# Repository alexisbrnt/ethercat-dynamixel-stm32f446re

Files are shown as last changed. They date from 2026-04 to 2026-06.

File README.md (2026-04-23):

# EtherCAT Communication for Dynamixel by STM32F446RE

> An embedded **EtherCAT slave node** built around the STM32F446RE, driving a Dynamixel XM430-W350 servomotor in real time.

---

## About

An embedded EtherCAT slave node based on the **STM32F446RE** microcontroller, designed to drive a **Dynamixel XM430-W350** servomotor through the Dynamixel Protocol 2.0. The STM32 interfaces with an EtherCAT master over SPI (via a LAN9252 slave controller) and translates incoming commands into UART/RS-485 frames sent to the motor.

This project is developed as part of an internship at **Heemskerk Innovative Technology (HIT)**, Delft, The Netherlands.

---

## Goal

Design and implement a new real-time communication architecture allowing an EtherCAT master to command a Dynamixel servomotor (position, velocity, etc.) and read back its live telemetry (position, velocity, current, temperature) with deterministic timing.

**Data path:**

```
EtherCAT Master  ──►  LAN9252 (SPI slave)  ──►  STM32F446RE  ──►  MAX485  ──►  Dynamixel XM430-W350
```

---

## Hardware

| Component | Reference |
|---|---|
| Microcontroller | STM32F446RE (ARM Cortex-M4 @ 180 MHz, 512 KB Flash, 128 KB SRAM) |
| Development board | Nucleo-F446RE (integrated ST-LINK) |
| EtherCAT slave controller | **EVB-LAN9252-SPI** (Microchip evaluation board) |
| Motor | Dynamixel XM430-W350 (Protocol 2.0) |
| UART ↔ RS-485 transceiver | MAX485 |
| Motor power supply | SMPS2Dynamixel |

---

## STM32F446RE Pinout

### Dynamixel communication (UART + RS-485)

| STM32 Pin | Function | Connected to |
|---|---|---|
| **PA9** | UART TX | MAX485 DI |
| **PA10** | UART RX | MAX485 RO |
| **PB3** | DE/RE (RS-485 direction control) | MAX485 DE + RE |

### EtherCAT communication (SPI to LAN9252)

| STM32 Pin | Function | Connected to |
|---|---|---|
| **PA5** | SPI SCK | LAN9252 SCK |
| **PA6** | SPI MISO | LAN9252 MISO |
| **PA7** | SPI MOSI | LAN9252 MOSI |
| **PB6** | SPI CS | LAN9252 CS |

---

## Configuration

| Parameter | Value |
|---|---|
| UART baudrate (STM32 ↔ Dynamixel) | **3,000,000 bauds** (3 Mbps) |
| Dynamixel protocol | **2.0** |
| Default motor ID | **1** |
| SPI frequency (STM32 ↔ LAN9252) | **11.25 MHz** |
| EtherCAT cycle time | **2 ms** |

---

## Usage

### 1. Flash the LAN9252 EEPROM (one-time setup)

Before the EtherCAT master can discover the slave with the correct identity (vendor ID, product code, PDO mapping, etc.), the LAN9252 EEPROM must be programmed with the project's ESI (EtherCAT Slave Information) binary.

The EEPROM image is provided in the firmware sources:

```
STM32_dynamixel/Src/ECAT/soes-esi/eeprom.hex
```

Flash it with the `eepromtool` utility provided by [SOEM](https://github.com/OpenEtherCATsociety/SOEM):

```bash
sudo ./eepromtool <your_network_interface> 1 -wi eeprom.hex
```

- The first argument `1` is the EtherCAT slave position on the bus.
- Replace `<your_network_interface>` (e.g. `eth0`) with the interface connected to the LAN9252.

This step is only required **once per LAN9252 board**, or whenever the ESI / PDO mapping is changed.

### 2. Build and flash the STM32 firmware

1. Open **STM32CubeIDE** 
2. `File → Open Projects from File System…` and select the `firmware/` folder.
3. Build the project: `Project → Build Project` (or `Ctrl+B`).
4. Connect the Nucleo-F446RE over USB and flash: `Run → Run` (or `F11` for debug mode).

### 3. Run the EtherCAT master and GUI

The `ec_motor.py` script is a single-program tool that launches the **EtherCAT master** (using `pysoem`) and a **PyQt5 graphical interface** in the same process. The master runs its cyclic loop (2 ms period) in a dedicated thread and communicates with the GUI through Qt signals.

The GUI allows the user to:

- select the motor **ID** and **control mode** (Position or Velocity),
- set a **target position** (0–4095) or **target velocity** (−200 to +200) through sliders,
- toggle the **torque** and the **LED** on the motor,
- monitor in real time the **present position, velocity, current, temperature**, the motor **state** (`IDLE`, `INIT`, `READY`, `RUNNING`, `ERROR`, `OFF`), the current **operating mode** and the **baudrate**.

**Dependencies** (tested on Linux, Ubuntu/Debian):

```bash
pip install -r scripts/requirements.txt
```

**Launch** (from the root of the repository):

```bash
sudo python3 scripts/ec_motor.py --ifname <your_network_interface>
```

#### Network interface — must be adapted to your machine

The EtherCAT master binds to a specific network interface (the one physically connected to the EtherCAT slave, typically a USB-to-Ethernet adapter). The interface name depends on your hardware and operating system, so **it must be changed in two places**:

1. In the **launch command**, via the `--ifname` argument.
2. In the **default value** inside `scripts/ec_motor.py` (the current hardcoded default is the interface used during development and will not match your setup).

To find the name of your own interface on Linux:

```bash
ip link show
```

Look for an entry matching the adapter you plugged in (often starting with `enx...` for USB-to-Ethernet, or `eth...` / `enp...` for built-in Ethernet).

**Other notes:**

- `sudo` is required because the EtherCAT master sends raw Ethernet frames directly on the network interface.

---

## Resources & references

- [Dynamixel XM430-W350 e-Manual](https://emanual.robotis.com/docs/en/dxl/x/xm430-w350/)
- [Dynamixel Protocol 2.0](https://emanual.robotis.com/docs/en/dxl/protocol2/)
- [STM32F446RE datasheet](https://www.st.com/en/microcontrollers-microprocessors/stm32f446re.html)
- [Microchip LAN9252 product page](https://www.microchip.com/en-us/product/lan9252)
- [EtherCAT Technology Group (ETG)](https://www.ethercat.org/)

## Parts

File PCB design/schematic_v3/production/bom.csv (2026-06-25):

Designator | Footprint | Quantity | Value | LCSC Part #
C1, C11, C13, C15, C16, C17, C20, C21, C24, C25, C27, C28, C31, C34, C35, C38, C40, C41, C42, C43, C45, C5 | 603 | 22 | 100n | C1525
C10 | 603 | 1 | 1n | C1588
C12, C18, C19, C36 | 603 | 4 | 1u | C15849
C14 | 603 | 1 | 470p | C1620
C2, C3, C4, C6 | 603 | 4 | 10p | C1634
C22, C23 | 603 | 2 | 18p | C1647
C26 | CP_Elec_5x5.4 | 1 | 47u | C7469972
C29, C39, C50 | 1206 | 3 | 10u | C13585
C30 | 1206 | 1 | 100n | C24497
C32, C33 | 603 | 2 | 27p | C107045
C37 | 603 | 1 | 4.7u | C19666
C44 | 603 | 1 | 270p | C1608
C46, C48 | C_Elec_4x5.8 | 2 | 27u | C413624
C47, C49 | 1206 | 2 | 22u | C12891
C51 | 603 | 1 | 56p | C107053
C7 | 603 | 1 | 0.022u | C21122
C8 | CP_Elec_5x5.4 | 1 | 10u | C7469956
C9 | CP_Elec_4x5.4 | 1 | 1u | C3348
D1, D2 | D_SOD-323F | 2 | PMEG3020EJ | C7472895
D3, D8 | SOT-143 | 2 | PRTR5V0U2X | C2827688
D4 | 603 | 1 | LED_Small | C2286
D5 | 603 | 1 | LED_Small | C2287
D6 | 603 | 1 | LED_Small | C2288
D7 | 603 | 1 | LED_Small | C2289
F1 | 2920L150_60MR | 1 | 2920L150_60MR | C22504886
FB1, FB2, FB3, FB4 | IND_BLM18_0603_MUR | 4 | BLM18EG221SN1D | C85827
FB5 | MMZ0603A471ET000 | 1 | MMZ0603A471ET000 | C502003
IC1 | LAN9252 | 1 | LAN9252 | C2758355
IC2 | MP5000ADQ-LF-Z | 1 | MP5000ADQ-LF-Z | C17698177
J1 | JST_EH_B4B-EH-A_1x04_P2.50mm_Vertical | 1 | Conn_01x04_Pin | C160258
J2 | JST_EH_B2B-EH-A_1x02_P2.50mm_Vertical | 1 | Conn_01x02_Pin | C160262
J3 | JST_EH_B4B-EH-A_1x04_P2.50mm_Vertical | 1 | connection_moteur | C160258
J4 | PinHeader_1x05_P1.27mm_Vertical | 1 | Conn_01x05_Pin | C22438102
J5 | JST_EH_B3B-EH-A_1x03_P2.50mm_Vertical | 1 | Conn_01x03_Pin | C160259
L1 | L_Bourns_SRR1260 | 1 | 18u | C2042399
L2 | L_Bourns-SRN4018 | 1 | 6.8u | C2044369
R1 | 603 | 1 | 47k | C25819
R10 | 805 | 1 | 120 | C17437
R11, R12 | 603 | 2 | 75 | C4275
R13 | 603 | 1 | 220 | C22962
R14, R46, R47 | 603 | 3 | 100 | C22775
R15, R17, R18, R24, R26, R27, R29, R3, R31, R37, R43, R44, R45 | 603 | 13 | 10k | C309083
R16 | 603 | 1 | 12.1k | C22864
R19 | 603 | 1 | 4.7k | C23162
R2, R4, R5, R6 | 603 | 4 | 49.9 | C23185
R20, R7 | 603 | 2 | 0 | C21189
R21, R22, R34, R36, R38, R39, R40, R41, R42 | 603 | 9 | 1k | C21190
R23 | 603 | 1 | 68k | C23231
R25, R8, R9 | 603 | 3 | 20k | C4184
R28 | 603 | 1 | 150k | C22807
R30, R32, R33 | 603 | 3 | 33 | C23140
R35 | 603 | 1 | 3.3k | C22978
S1, S2 | B3U1100PM | 2 | B3U-1100PM | C6467298
T1 | 7490100110A | 1 | 7490100110A | C55061081
TP1, TP2, TP3, TP4, TP5, TP6, TP7, TP8, TP9 | TestPoint_Pad_D1.0mm | 9 | TestPoint
U1 | SN74LVC3G17DCTRE4 | 1 | SN74LVC3G17DCTRE4 | C19948350
U3 | 24FC512_I_ST | 1 | 24FC512-I/ST | C619635
U4 | LMR14030SQDPRTQ1 | 1 | LMR14030SQDPRTQ1 | C425925
U5 | LQFP-64_10x10mm_P0.5mm | 1 | STM32F446RETx | C69336
U6 | TSOT-23-6 | 1 | AP63203WU | C780769
U7 | SOIC-8_3.9x4.9mm_P1.27mm | 1 | MAX3485 | C9943
Y2 | ABM3-20.000MHZ-D2Y-T | 1 | ABM3-20.000MHZ-D2Y-T | C596863
Y3 | ABM3-25.000MHZ-D2Y-T | 1 | ABM3-25.000MHZ-D2Y-T | C148312

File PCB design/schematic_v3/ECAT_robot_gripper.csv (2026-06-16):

Reference | Qty | Value | DNP | Exclude from BOM | Exclude from Board | Footprint | Datasheet
C1,C6,C11,C13,C15,C16,C17,C21,C22,C28,C30,C33,C35 | 13 | 0.1u |  |  |  | Capacitor_SMD:C_0603_1608Metric
C2,C3,C4,C5 | 4 | 10p |  |  |  | Capacitor_SMD:C_0603_1608Metric
C7 | 1 | 0.022u |  |  |  | Capacitor_SMD:C_0603_1608Metric
C8,C10,C18 | 3 | 47u |  |  |  | Capacitor_SMD:CP_Elec_5x5.4
C9 | 1 | 1n |  |  |  | Capacitor_SMD:C_0603_1608Metric
C12,C19,C20,C44 | 4 | 1u |  |  |  | Capacitor_SMD:C_0603_1608Metric
C14 | 1 | 470p |  |  |  | Capacitor_SMD:C_0603_1608Metric
C26,C27 | 2 | 18p |  |  |  | Capacitor_SMD:C_0603_1608Metric
C29,C56 | 2 | 10u |  |  |  | Capacitor_SMD:C_1206_3216Metric
C38 | 1 | 100n |  |  |  | Capacitor_SMD:C_1206_3216Metric
C39,C42,C43,C46,C47,C48,C50,C51,C57 | 9 | 100n |  |  |  | Capacitor_SMD:C_0603_1608Metric
C40,C41 | 2 | 20p |  |  |  | Capacitor_SMD:C_0603_1608Metric
C45 | 1 | 4.7u |  |  |  | Capacitor_SMD:C_0603_1608Metric
C52 | 1 | 270p |  |  |  | Capacitor_SMD:C_0603_1608Metric
C53,C55 | 2 | 27u |  |  |  | Capacitor_SMD:C_1206_3216Metric
C58,C59 | 2 | 22u |  |  |  | Capacitor_SMD:C_1206_3216Metric
D1,D2,D3 | 3 | B340 |  |  |  | Diode_SMD:D_SMC | http://www.jameco.com/Jameco/Products/ProdDS/1538777.pdf
FB1,FB2,FB3,FB4 | 4 | BLM18EG221SN1D |  |  |  | footprints:IND_BLM18_0603_MUR | BLM18EG221SN1D
FB5 | 1 | MMZ0603A471ET000 |  |  |  | footprints:MMZ0603A471ET000 | https://product.tdk.com/system/files/dam/doc/product/emc/emc/beads/catalog/beads_commercial_signal_mmz0603-e_en.pdf
IC1 | 1 | LAN9252 |  |  |  | footprints:LAN9252
J1 | 1 | Conn_01x04_Pin |  |  |  | Connector_JST:JST_EH_B4B-EH-A_1x04_P2.50mm_Vertical
J2 | 1 | connection_moteur |  |  |  | Connector_JST:JST_EH_B4B-EH-A_1x04_P2.50mm_Vertical
J3 | 1 | Conn_01x05_Pin |  |  |  | Connector_PinHeader_1.27mm:PinHeader_1x05_P1.27mm_Vertical
J4 | 1 | Conn_01x03_Pin |  |  |  | Connector_PinHeader_1.27mm:PinHeader_1x03_P1.27mm_Vertical
J5 | 1 | Conn_01x02_Pin |  |  |  | Connector_JST:JST_EH_B2B-EH-A_1x02_P2.50mm_Vertical
L1 | 1 | 18u |  |  |  | Inductor_SMD:L_Bourns_SRR1260
L3 | 1 | 6.8u |  |  |  | Inductor_SMD:L_Bourns-SRN4018
Q1 | 1 | AO3400A |  |  |  | Package_TO_SOT_SMD:SOT-23 | http://www.aosmd.com/pdfs/datasheet/AO3400A.pdf
R1,R4,R5,R6 | 4 | 49.9 |  |  |  | Resistor_SMD:R_0603_1608Metric
R2 | 1 | 47k |  |  |  | Resistor_SMD:R_0603_1608Metric
R3,R14,R15,R17,R18,R24,R26,R27,R29,R31 | 10 | 10k |  |  |  | Resistor_SMD:R_0603_1608Metric
R7,R20 | 2 | 0 |  |  |  | Resistor_SMD:R_0603_1608Metric
R8,R9,R25 | 3 | 20k |  |  |  | Resistor_SMD:R_0603_1608Metric
R10 | 1 | 120 |  |  |  | Resistor_SMD:R_0805_2012Metric
R11,R12 | 2 | 75 |  |  |  | Resistor_SMD:R_0603_1608Metric
R13 | 1 | 220 |  |  |  | Resistor_SMD:R_0603_1608Metric
R16 | 1 | 12.1k |  |  |  | Resistor_SMD:R_0603_1608Metric
R19 | 1 | 4.7k |  |  |  | Resistor_SMD:R_0603_1608Metric
R21,R22 | 2 | 2k |  |  |  | Resistor_SMD:R_0603_1608Metric
R23 | 1 | 68k |  |  |  | Resistor_SMD:R_0603_1608Metric
R28 | 1 | 150k |  |  |  | Resistor_SMD:R_0603_1608Metric
R30,R32,R33 | 3 | 33 |  |  |  | Resistor_SMD:R_0603_1608Metric
S1 | 1 | TS40-66-43-BK-260-SMT-TR |  |  |  | footprints:TS40-66-43-BK-260-SMT-TR | https://www.sameskydevices.com/product/resource/ts40.pdf
U1 | 1 | HX1188NL |  |  |  | footprints:HX1188NL | HX1188NL
U2 | 1 | SP3485CN |  |  |  | Package_SO:SOIC-8_3.9x4.9mm_P1.27mm | http://www.icbase.com/pdf/SPX/SPX00480106.pdf
U3 | 1 | 24FC512-I/ST |  |  |  | footprints:24FC512_I_ST | 24FC512-I/ST
U4 | 1 | LMR14030SQDPRTQ1 |  |  |  | footprints:LMR14030SQDPRTQ1 | https://www.ti.com/lit/gpn/lmr14030-q1
U5 | 1 | STM32F446RETx |  |  |  | Package_QFP:LQFP-64_10x10mm_P0.5mm | https://www.st.com/resource/en/datasheet/stm32f446re.pdf
U7 | 1 | AP63203WU |  |  |  | Package_TO_SOT_SMD:TSOT-23-6 | https://www.diodes.com/assets/Datasheets/AP63200-AP63201-AP63203-AP63205.pdf
Y1 | 1 | 25MHz |  |  |  | Crystal:Crystal_SMD_HC49-SD
Y2 | 1 | 8MHz |  |  |  | Crystal:Crystal_SMD_HC49-SD

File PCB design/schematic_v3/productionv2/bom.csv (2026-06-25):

Designator | Footprint | Quantity | Value | LCSC Part #
C1, C11, C13, C15, C16, C17, C20, C21, C24, C25, C27, C28, C31, C34, C35, C38, C40, C41, C42, C43, C45, C5 | 603 | 22 | 100n | C1590
C10 | 603 | 1 | 1n | C1588
C12, C18, C19, C36 | 603 | 4 | 1u | C15849
C14 | 603 | 1 | 470p | C1620
C2, C3, C4, C6 | 603 | 4 | 10p | C1634
C22, C23 | 603 | 2 | 18p | C1647
C26 | CP_Elec_5x5.4 | 1 | 47u | C7469972
C29, C39, C50 | 1206 | 3 | 10u | C13585
C30 | 1206 | 1 | 100n | C24497
C32, C33 | 603 | 2 | 27p | C107045
C37 | 603 | 1 | 4.7u | C19666
C44 | 603 | 1 | 270p | C1608
C46, C48 | 1206 | 2 | 27u
C47, C49 | 1206 | 2 | 22u
C51 | 603 | 1 | 56p
C7 | 603 | 1 | 0.022u
C8 | CP_Elec_5x5.4 | 1 | 10u
C9 | CP_Elec_5x5.4 | 1 | 1u
D1, D2 | D_SOD-323F | 2 | PMEG3020EJ
D3, D8 | SOT-143 | 2 | PRTR5V0U2X
D4, D5, D6, D7 | 201 | 4 | LED_Small
F1 | 2920L150_60MR | 1 | 2920L150_60MR
FB1, FB2, FB3, FB4 | IND_BLM18_0603_MUR | 4 | BLM18EG221SN1D
FB5 | MMZ0603A471ET000 | 1 | MMZ0603A471ET000
IC1 | LAN9252 | 1 | LAN9252
IC2 | MP5000ADQ-LF-Z | 1 | MP5000ADQ-LF-Z
J1 | JST_EH_B4B-EH-A_1x04_P2.50mm_Vertical | 1 | Conn_01x04_Pin
J2 | JST_EH_B2B-EH-A_1x02_P2.50mm_Vertical | 1 | Conn_01x02_Pin
J3 | JST_EH_B4B-EH-A_1x04_P2.50mm_Vertical | 1 | connection_moteur
J4 | PinHeader_1x05_P1.27mm_Vertical | 1 | Conn_01x05_Pin
J5 | JST_EH_B3B-EH-A_1x03_P2.50mm_Vertical | 1 | Conn_01x03_Pin
L1 | L_Bourns_SRR1260 | 1 | 18u
L2 | L_Bourns-SRN4018 | 1 | 6.8u
R1 | 603 | 1 | 47k
R10 | 805 | 1 | 120
R11, R12 | 603 | 2 | 75
R13 | 603 | 1 | 220
R14, R46, R47 | 603 | 3 | 100
R15, R17, R18, R24, R26, R27, R29, R3, R31, R37, R43, R44, R45 | 603 | 13 | 10k
R16 | 603 | 1 | 12.1k
R19 | 603 | 1 | 4.7k
R2, R4, R5, R6 | 603 | 4 | 49.9
R20, R7 | 603 | 2 | 0
R21, R22, R34, R36, R38, R39, R40, R41, R42 | 603 | 9 | 1k
R23 | 603 | 1 | 68k
R25, R8, R9 | 603 | 3 | 20k
R28 | 603 | 1 | 150k
R30, R32, R33 | 603 | 3 | 33
R35 | 603 | 1 | 3.3k
S1, S2 | B3U1100PM | 2 | B3U-1100PM
T1 | 7490100110A | 1 | 7490100110A
TP1, TP2, TP3, TP4, TP5, TP6, TP7, TP8, TP9 | TestPoint_Pad_D1.0mm | 9 | TestPoint
U1 | SN74LVC3G17DCTRE4 | 1 | SN74LVC3G17DCTRE4
U3 | 24FC512_I_ST | 1 | 24FC512-I/ST
U4 | LMR14030SQDPRTQ1 | 1 | LMR14030SQDPRTQ1
U5 | LQFP-64_10x10mm_P0.5mm | 1 | STM32F446RETx
U6 | TSOT-23-6 | 1 | AP63203WU
U7 | SOIC-8_3.9x4.9mm_P1.27mm | 1 | MAX3485
Y2 | ABM3-20.000MHZ-D2Y-T | 1 | XTAL_ABM3-20.000MHZ-D2Y-T
Y3 | ABM3-25.000MHZ-D2Y-T | 1 | XTAL_ABM3-25.000MHZ-D2Y-T

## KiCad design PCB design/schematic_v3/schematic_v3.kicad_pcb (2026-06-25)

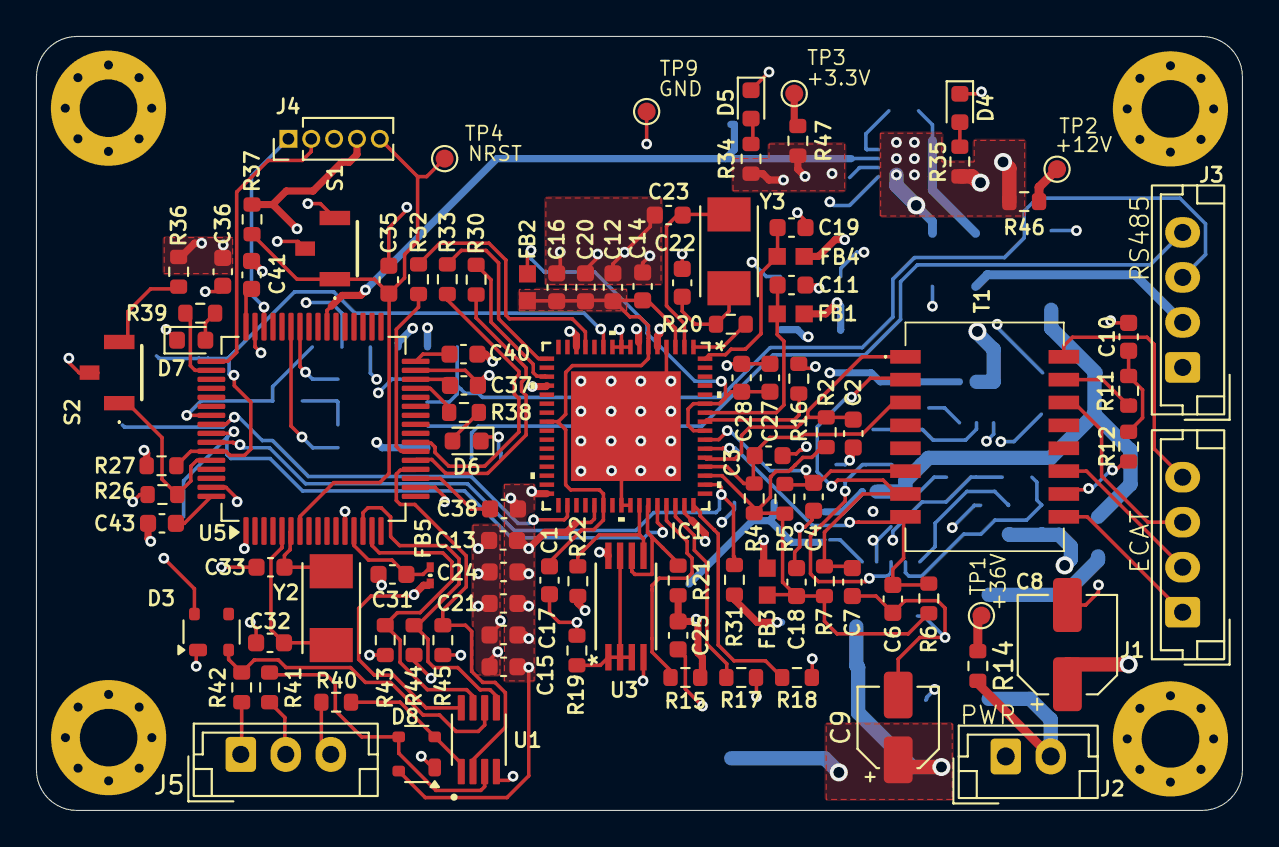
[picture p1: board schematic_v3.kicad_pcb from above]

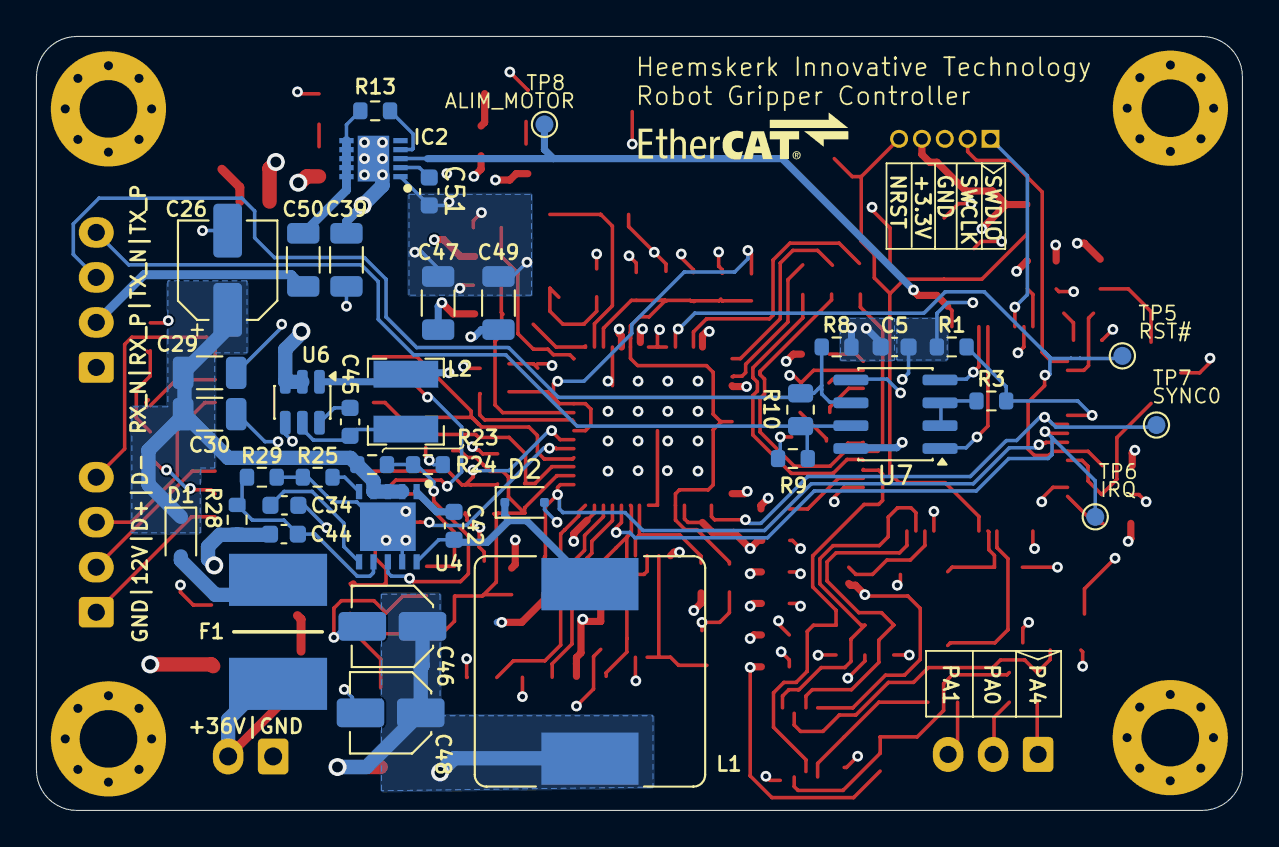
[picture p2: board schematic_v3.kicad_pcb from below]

Board: 4 copper layers, 67.0 x 43.0 mm, 145 parts (39 on the bottom side), 93 nets.

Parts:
C1, C5, C11, C13, C15, C16, C17, C20, C21, C24, C25, C27, C28, C31, C34, C35, C38, C40, C41, C42, C43, C45: 100n; C_0603_1608Metric
C2, C3, C4, C6: 10p; C_0603_1608Metric
C7: 0.022u; C_0603_1608Metric
C8: 10u; CP_Elec_5x5.4
C9: 1u; CP_Elec_4x5.4
C10: 1n; C_0603_1608Metric
C12, C18, C19, C36: 1u; C_0603_1608Metric
C14: 470p; C_0603_1608Metric
C22, C23: 18p; C_0603_1608Metric
C26: 47u; CP_Elec_5x5.4
C29, C39, C50: 10u; C_1206_3216Metric
C30: 100n; C_1206_3216Metric
C32, C33: 27p; C_0603_1608Metric
C37: 4.7u; C_0603_1608Metric
C44: 270p; C_0603_1608Metric
C46, C48: 27u; C_Elec_4x5.8
C47, C49: 22u; C_1206_3216Metric
C51: 56p; C_0603_1608Metric
D1, D2: PMEG3020EJ; D_SOD-323F
D3, D8: PRTR5V0U2X; SOT-143
D4, D5, D6, D7: LED_Small; LED_0603_1608Metric
F1: 2920L150_60MR
FB1, FB2, FB3, FB4: BLM18EG221SN1D; IND_BLM18_0603_MUR
FB5: MMZ0603A471ET000
H1, H2, H3, H4: MountingHole; MountingHole_3.2mm_M3_Pad_Via
IC1: LAN9252
IC2: SON50P300X300X100-11N-D; MP5000ADQ-LF-Z
J1: Conn_01x04_Pin; JST_EH_B4B-EH-A_1x04_P2.50mm_Vertical
J2: Conn_01x02_Pin; JST_EH_B2B-EH-A_1x02_P2.50mm_Vertical
J3: connection_moteur; JST_EH_B4B-EH-A_1x04_P2.50mm_Vertical
J4: Conn_01x05_Pin; PinHeader_1x05_P1.27mm_Vertical
J5: Conn_01x03_Pin; JST_EH_B3B-EH-A_1x03_P2.50mm_Vertical
L1: 18u; L_Bourns_SRR1260
L2: 6.8u; L_Bourns-SRN4018
R1: 47k; R_0603_1608Metric
R2, R4, R5, R6: 49.9; R_0603_1608Metric
R3, R15, R17, R18, R24, R26, R27, R29, R31, R37, R43, R44, R45: 10k; R_0603_1608Metric
R7, R20: 0; R_0603_1608Metric
R8, R9, R25: 20k; R_0603_1608Metric
R10: 120; R_0805_2012Metric
R11, R12: 75; R_0603_1608Metric
R13: 220; R_0603_1608Metric
R14, R46, R47: 100; R_0603_1608Metric
R16: 12.1k; R_0603_1608Metric
R19: 4.7k; R_0603_1608Metric
R21, R22, R34, R36, R38, R39, R40, R41, R42: 1k; R_0603_1608Metric
R23: 68k; R_0603_1608Metric
R28: 150k; R_0603_1608Metric
R30, R32, R33: 33; R_0603_1608Metric
R35: 3.3k; R_0603_1608Metric
S1, S2: B3U-1100PM; B3U1100PM
T1: 7490100110A
TP1, TP2, TP3, TP4, TP5, TP6, TP7, TP8, TP9: TestPoint; TestPoint_Pad_D1.0mm
U1: SN74LVC3G17DCTRE4
U3: 24FC512-I/ST; 24FC512_I_ST
U4: LMR14030SQDPRTQ1
U5: STM32F446RETx; LQFP-64_10x10mm_P0.5mm
U6: AP63203WU; TSOT-23-6
U7: MAX3485; SOIC-8_3.9x4.9mm_P1.27mm
Y2: ABM3-20.000MHZ-D2Y-T
Y3: ABM3-25.000MHZ-D2Y-T

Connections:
+3.3V: C5.1, C13.1, C15.1, C17.1, C21.1, C24.1, C25.2, C36.2, C38.1, C40.1, C41.1, C43.1, C47.1, C49.1, D3.4 (VCC), D8.4 (VCC), FB1.1, FB3.2, FB4.2, FB5.1, IC1.5 (VDD33), IC1.7 (REG_EN), IC1.14 (VDDIO0), IC1.20 (VDDIO1), IC1.32 (VDDIO2), IC1.37 (VDDIO3), IC1.47 (VDDIO4), J4.4, L2.2, R8.2, R15.1, R21.2, R22.2, R27.1, R31.1, R34.1, R36.1, R37.2, R47.2, U1.8 (VCC), U3.8 (VCC), U5.1 (VBAT), U6.1 (FB), U7.8 (VCC)
+12V: C8.1, C9.1, C39.1, C44.1, C46.1, C48.1, IC2.11 (VCC), L1.2, R28.1, R35.1, R46.2, U6.2 (EN), U6.3 (IN)
+36V: F1.1, J2.2, R14.2
/ALIM_MOTOR: IC2.3 (ENABLE/FAULT), TP8.1 (1_1), U5.39 (PC8)
/AVDD: C31.1, FB5.2, U5.13 (VDDA)
/AX: R19.1, U3.1 (A0), U3.2 (A1), U3.3 (A2), U3.7 (WP)
/BOOT: C42.1, U4.1 (BOOT)
/BOOT0: R26.1, S2.1 (COM), U5.60 (BOOT0)
/BST: C45.2, U6.6 (BST)
/CMT: C10.1, R11.1, R12.1
/CMT1: R11.2, T1.15 (CTX)
/CMT2: R12.2, T1.10 (CRX)
/DATA+: J3.3, R8.1, R10.2, U7.6 (A)
/DATA-: J3.4, R9.2, R10.1, U7.7 (B)
/DE/RE: R3.1, U7.2 (~RE), U7.3 (DE)
/DI: U5.42 (PA9), U7.4 (DI)
/FB: C44.2, R28.2, R29.1, U4.7 (FB)
/I2C_SCL: IC1.43 (EESCL/TCK), R21.1, U3.6 (SCL)
/I2C_SDL: IC1.42 (EESDA/TMS), R22.1, U3.5 (SDA)
/IRQ: IC1.44 (IRQ), TP6.1 (1_1), U5.57 (PB5)
/MISO: IC1.13 (D1/AD1/EOF/SO/SIO1), R32.1
/MOSI: IC1.17 (D0/AD0/WD_STATE/SI/SIO0), R33.1
/NRST: C35.2, J4.5, R37.1, S1.1 (COM), TP4.1 (1_1), U5.7 (NRST)
/OSCI: IC1.1 (OSCI), R20.1
/OSCO: C23.2, IC1.2 (OSCO), Y3.1
/PA0: R44.1, U1.5 (2Y), U5.14 (PA0)
/PA1: R43.1, U1.7 (1Y), U5.15 (PA1)
/PA4: R45.1, U1.2 (3Y), U5.20 (PA4)
/PA5: R30.2, U5.21 (PA5)
/PA6: R32.2, U5.22 (PA6)
/PA7: R33.2, U5.23 (PA7)
/PA15: R39.1, U5.50 (PA15)
/PB10: R38.1, U5.29 (PB10)
/PGOOD: R23.2, R24.1, U4.8 (PGOOD)
/PH0: C32.2, U5.5 (PH0), Y2.2
/PH1: C33.2, U5.6 (PH1), Y2.1
/RBIAS: IC1.57 (RBIAS), R16.2
/RCT: C7.1, R7.2, T1.2 (CTD), T1.7 (CRD)
/RO: U5.43 (PA10), U7.1 (RO)
/RS485_MODE: R1.2, R3.2, U5.55 (PB3)
/RST#: IC1.11 (RST#), R27.2, TP5.1 (1_1), U5.59 (PB7)
/RT_SYNC: R25.1, U4.5 (RT_SYNC)
/RXA_N: C6.1, IC1.54 (RXNA), R6.2, T1.8 (RD-)
/RXA_P: C4.1, IC1.55 (RXPA), R5.2, T1.6 (RD+)
/RX_N: J1.1, T1.9 (RX-)
/RX_P: J1.2, T1.11 (RX+)
/SCK: IC1.19 (D9/AD9/LATCH_IN/SCK), R30.1
/SCS#: IC1.50 (D5/AD5/OUTVALID/SCS#), R31.2, U5.58 (PB6)
/SS: C34.1, U4.6 (SS)
/SW: C45.1, L2.1, U6.5 (SW)
/SWCLK: J4.2, U5.49 (PA14)
/SWDIO: J4.1, U5.46 (PA13)
/SYNC0: IC1.34 (SYNC0/LATCH0), TP7.1 (1_1), U5.56 (PB4)
/TXA_N: C3.1, IC1.52 (TXNA), R4.2, T1.3 (TD-)
/TXA_P: C2.1, IC1.53 (TXPA), R2.2, T1.1 (TD+)
/TX_N: J1.3, T1.14 (TX-)
/TX_P: J1.4, T1.16 (TX+)
/VCAP_1: C37.1, U5.30 (VCAP_1)
/VDD12TX1: C27.1, C28.1, FB2.2, IC1.56 (VDD12TX1), IC1.59 (VDD12TX2)
/VDD19: C38.2, U5.19 (VDD)
/VDD32: C40.2, U5.32 (VDD)
/VDD33BIAS: C11.2, FB1.2, IC1.58 (VDD33BIAS)
/VDD33TXRX1: C18.1, FB3.1, IC1.51 (VDD33TXRX1), R2.1, R4.1, R5.1, R6.1, R7.1
/VDD33TXRX2: C19.1, FB4.1, IC1.64 (VDD33TXRX2)
/VDD48: C41.2, U5.48 (VDD)
/VDD64: C43.2, U5.64 (VDD)
/VDDCR: C1.2, C12.1, C14.1, C16.1, C20.1, FB2.1, IC1.3 (OSCVDD12), IC1.6 (VDDCR0), IC1.24 (VDDCR1), IC1.38 (VDDCR2)
/VIN: C26.1, C29.1, C30.1, D1.1 (K), R23.1, U4.2 (VIN), U4.3 (VIN), U4.4 (EN)
GND: C1.1, C2.2, C3.2, C4.2, C5.2, C6.2, C7.2, C8.2, C9.2, C11.1, C12.2, C13.2, C14.2, C15.2, C16.2, C17.2, C18.2, C19.2, C20.2, C21.2, C22.1, C23.1, C24.2, C25.1, C26.2, C27.2, C28.2, C29.2, C30.2, C31.2, C32.1, C33.1, C34.2, C35.1, C36.1, C37.2, C39.2, C46.2, C47.2, C48.2, C49.2, C51.1, D2.2 (A), D3.1 (GND), D4.1 (K), D5.1 (K), D6.1 (K), D7.1 (K), D8.1 (GND), IC1.4 (OSCVSS), IC1.8 (FXLOSEN), IC1.9 (FXSDA/FXLOSA/FXSDENA), IC1.10 (FXSDB/FXLOSB/FXSDENB), IC1.40 (D8/AD8/DIGIO2/GPI2/GPO2/MII_MDIO), IC1.41 (TESTMODE), IC1.65 (VSS), IC2.1 (GND), J2.1, J3.1, J4.3, R1.1, R9.1, R16.1, R17.1, R18.1, R19.2, R24.2, R25.2, R26.2, R29.2, R43.2, R44.2, R45.2, S1.2 (NO), S1.3 (GND), S2.3 (GND), TP9.1 (1_1), U1.4 (GND), U3.4 (VSS), U4.9 (GND), U4.11 (PAD), U5.12 (VSSA), U5.18 (VSS), U5.31 (VSS), U5.47 (VSS), U5.63 (VSS), U6.4 (GND), U7.5 (GND)
unnamed: C22.2, R20.2, Y3.2
unnamed: D1.2 (A), F1.2
unnamed: C42.2, D2.1 (K), L1.1, U4.10 (SW)
unnamed: D3.2 (I/O1), R42.1, U1.6 (3A)
unnamed: D4.2 (A), R35.2
unnamed: D5.2 (A), R34.2
unnamed: D6.2 (A), R38.2
unnamed: D7.2 (A), R39.2
unnamed: D8.2 (I/O1), R40.1, U1.1 (1A)
unnamed: D8.3 (I/O2), R41.1, U1.3 (2A)
unnamed: IC1.48 (LINKACTLED0/TDO/CHIP_MODE0), R18.2
unnamed: IC1.46 (LINKACTLED1/TDI/CHIP_MODE1), R17.2
unnamed: IC1.45 (RUNLED/E2PSIZE), R15.2
unnamed: C51.2, IC2.2 (DV/DT)
unnamed: IC2.4 (I-LIMIT), R13.1
unnamed: C50.1, IC2.6 (SOURCE_1), IC2.7 (SOURCE_2), IC2.8 (SOURCE_3), IC2.9 (SOURCE_4), IC2.10 (SOURCE_5), R13.2
unnamed: C50.2, J3.2
unnamed: J5.1, R42.2
unnamed: J5.2, R41.2
unnamed: J5.3, R40.2
unnamed: R14.1, TP1.1 (1_1)
unnamed: R46.1, TP2.1 (1_1)
unnamed: R47.1, TP3.1 (1_1)
unnamed: R36.2, S2.2 (NO)

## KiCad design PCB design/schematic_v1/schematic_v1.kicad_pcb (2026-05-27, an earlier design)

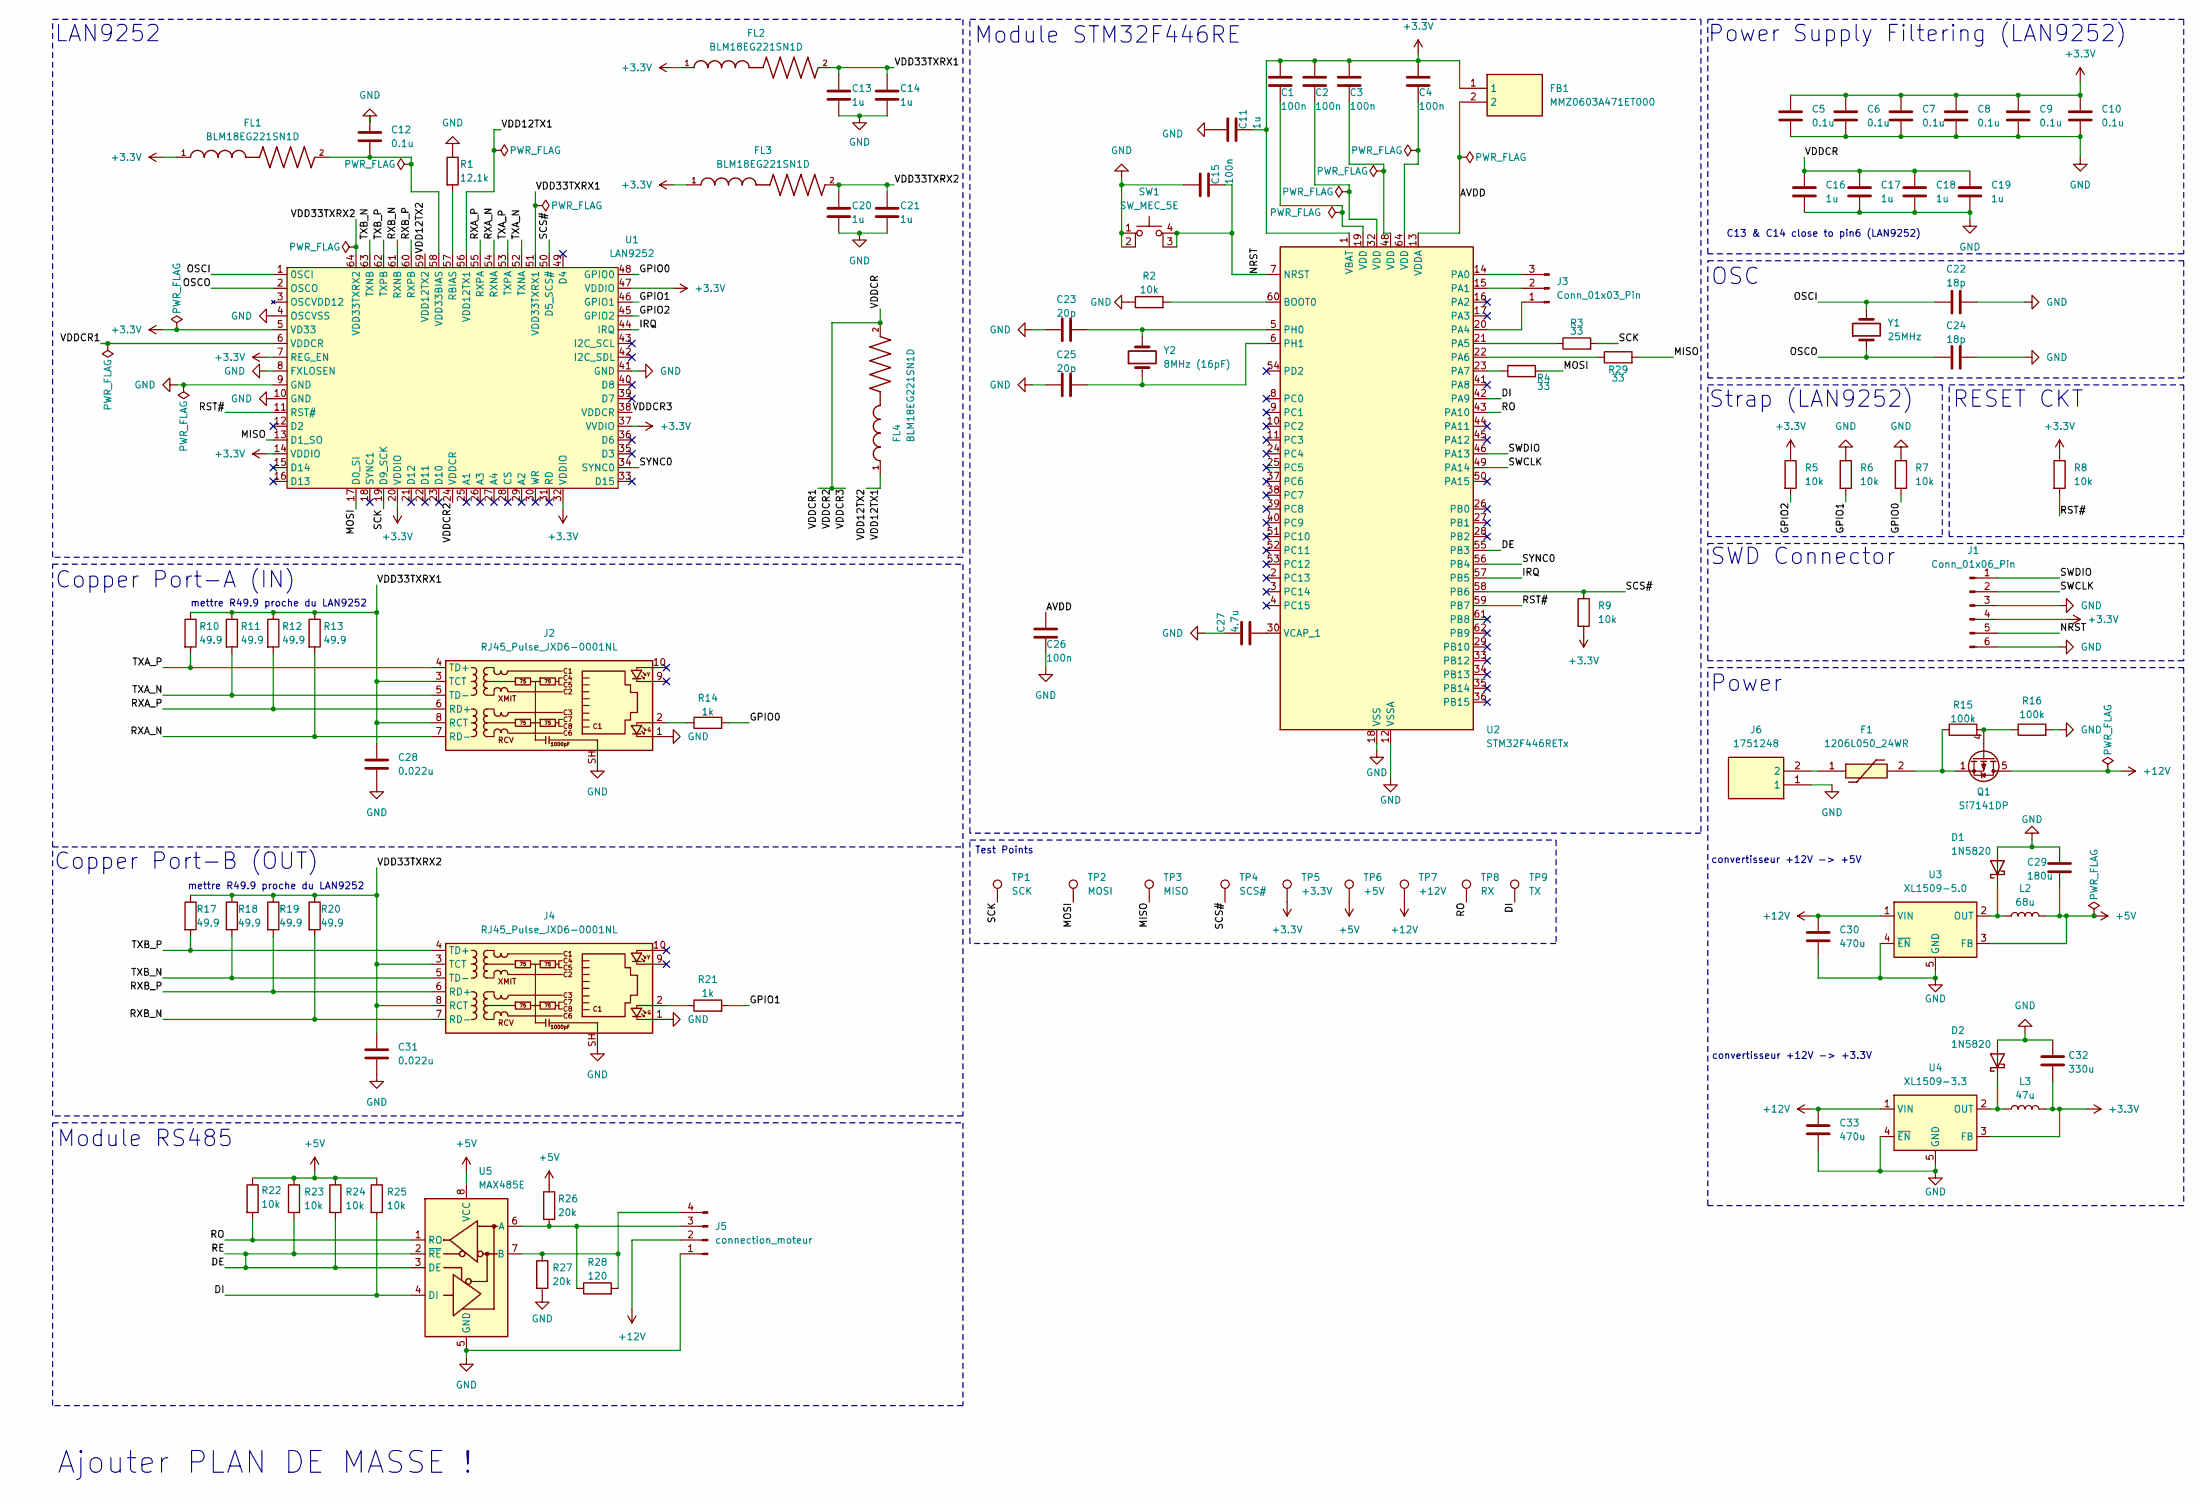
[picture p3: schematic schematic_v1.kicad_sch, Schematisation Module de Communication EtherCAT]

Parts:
C1: 100n; BNC_Amphenol_B6252HB-NPP3G-50_Horizontal
C2, C3, C4, C15, C26: 100n; C_0805_2012Metric_Pad1.18x1.45mm_HandSolder
C5, C6, C7, C8, C9, C10, C12: 0.1u; C_0805_2012Metric_Pad1.18x1.45mm_HandSolder
C11, C13, C14, C16, C17, C18, C19, C20, C21: 1u; C_0805_2012Metric_Pad1.18x1.45mm_HandSolder
C22, C24: 18p; C_0805_2012Metric_Pad1.18x1.45mm_HandSolder
C23, C25: 20p; C_0805_2012Metric_Pad1.18x1.45mm_HandSolder
C27: 4.7u; C_Elec_5x5.4
C28, C31: 0.022u; C_0805_2012Metric_Pad1.18x1.45mm_HandSolder
C29: 180u; C_0805_2012Metric_Pad1.18x1.45mm_HandSolder
C30: 470u; C_Elec_5x5.4
C32: 330u; C_Elec_5x5.4
C33: 470u; C_0805_2012Metric_Pad1.18x1.45mm_HandSolder
D1, D2: 1N5820; D_DO-201AD_P15.24mm_Horizontal
F1: 1206L050_24WR; 1206L075132WR; Mouser Part Number 576-1206L050/24WR
FB1: MMZ0603A471ET000; BEADC0603X33N; Mouser Part Number 810-MMZ0603A471ET000
FL1, FL2, FL3, FL4: BLM18EG221SN1D; BEADC1608X95N
J1: Conn_01x06_Pin; PinHeader_2x03_P1.27mm_Vertical
J2, J4: RJ45_Pulse_JXD6-0001NL; RJ45_Pulse_JXD6-0001NL_Horizontal
J3: Conn_01x03_Pin; PinHeader_1x03_P1.27mm_Vertical
J5: connection_moteur; JST_EH_B4B-EH-A_1x04_P2.50mm_Vertical
J6: 1751248; Mouser Part Number 651-1751248
L2: 68u; L_Wurth_WE-LQSH-4020
L3: 47u; L_Wurth_WE-LQSH-4020
Q1: Si7141DP; PowerPAK_SO-8_Single
R1: 12.1k; R_0805_2012Metric_Pad1.20x1.40mm_HandSolder
R2, R5, R6, R7, R8, R9, R22, R23, R24, R25: 10k; R_0805_2012Metric_Pad1.20x1.40mm_HandSolder
R3, R4, R29: 33; R_0805_2012Metric_Pad1.20x1.40mm_HandSolder
R10, R11, R12, R13, R17, R18, R19, R20: 49.9; R_0805_2012Metric_Pad1.20x1.40mm_HandSolder
R14, R21: 1k; R_0805_2012Metric_Pad1.20x1.40mm_HandSolder
R15, R16: 100k; R_0805_2012Metric_Pad1.20x1.40mm_HandSolder
R26, R27: 20k; R_0805_2012Metric_Pad1.20x1.40mm_HandSolder
R28: 120; R_0805_2012Metric_Pad1.20x1.40mm_HandSolder
SW1: SW_MEC_5E; SW_MEC_5GSH9
TP1: SCK; TestPoint_Keystone_5015_Micro_Mini
TP2: MOSI; TestPoint_Keystone_5015_Micro_Mini
TP3: MISO; TestPoint_Keystone_5015_Micro_Mini
TP4: SCS#; TestPoint_Keystone_5015_Micro_Mini
TP5: +3.3V; TestPoint_Keystone_5015_Micro_Mini
TP6: +5V; TestPoint_Keystone_5015_Micro_Mini
TP7: +12V; TestPoint_Keystone_5015_Micro_Mini
TP8: RX; TestPoint_Keystone_5015_Micro_Mini
TP9: TX; TestPoint_Keystone_5015_Micro_Mini
U1: LAN9252; QFN-64-1EP_9x9mm_P0.5mm_EP6x6mm
U2: STM32F446RETx; LQFP-64_10x10mm_P0.5mm
U3: XL1509-5.0; SOIC-8_3.9x4.9mm_P1.27mm
U4: XL1509-3.3; SOIC-8_3.9x4.9mm_P1.27mm
U5: MAX485E; SOIC-8_3.9x4.9mm_P1.27mm
Y1: 25MHz; Crystal_SMD_HC49-SD
Y2: 8MHz (16pF); Crystal_SMD_HC49-SD

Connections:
+3.3V: C1.1, C2.1, C3.1, C4.1, C5.1, C6.1, C7.1, C8.1, C9.1, C10.1, C11.2, C32.2, FB1.1, FL1.1, FL2.1, FL3.1, J1.4, L3.2, R5.1, R8.1, R9.2, TP5.1, U1.5 (VD33), U1.7 (REG_EN), U1.14 (VDDIO), U1.20 (VDDIO), U1.32 (VDDIO), U1.37 (VVDIO), U1.47 (VDDIO), U2.1 (VBAT), U4.3 (FB)
+5V: C29.2, L2.2, R22.1, R23.1, R24.1, R25.1, R26.1, TP6.1, U3.3 (FB), U5.8 (VCC)
+12V: C30.1, C33.1, J5.2, Q1.5 (D), TP7.1, U3.1 (VIN), U4.1 (VIN)
/AVDD: C26.1, FB1.2, U2.13 (VDDA)
/DE: R23.2, R24.2, U2.55 (PB3), U5.2 (~RE), U5.3 (DE)
/DI: R25.2, TP9.1, U2.42 (PA9), U5.4 (DI)
/GPIO0: R7.2, R14.2, U1.48 (GPIO0)
/GPIO1: R6.2, R21.2, U1.46 (GPIO1)
/GPIO2: R5.2, U1.45 (GPIO2)
/IRQ: U1.44 (IRQ), U2.57 (PB5)
/MISO: R29.2, TP3.1, U1.13 (D1_SO)
/MOSI: R4.2, TP2.1, U1.17 (D0_SI)
/NRST: C15.2, J1.5, SW1.3 (K), SW1.4 (A), U2.7 (NRST)
/OSCI: C22.2, U1.1 (0SCI), Y1.2
/OSCO: C24.2, U1.2 (OSCO), Y1.1
/RO: R22.2, TP8.1, U2.43 (PA10), U5.1 (RO)
/RST#: R8.2, U1.11 (RST#), U2.59 (PB7)
/RXA_N: J2.7 (RD-), R13.2, U1.54 (RXNA)
/RXA_P: J2.6 (RD+), R12.2, U1.55 (RXPA)
/RXB_N: J4.7 (RD-), R20.2, U1.61 (RXNB)
/RXB_P: J4.6 (RD+), R19.2, U1.60 (RXPB)
/SCK: R3.2, TP1.1, U1.19 (D9_SCK)
/SCS#: R9.1, TP4.1, U1.50 (D5_SCS#), U2.58 (PB6)
/SYNC0: U1.34 (SYNC0), U2.56 (PB4)
/TXA_N: J2.5 (TD-), R11.2, U1.52 (TXNA)
/TXA_P: J2.4 (TD+), R10.2, U1.53 (TXPA)
/TXB_N: J4.5 (TD-), R18.2, U1.63 (TXNB)
/TXB_P: J4.4 (TD+), R17.2, U1.62 (TXPB)
/VDD12TX1: FL4.1, U1.56 (VDD12TX1), U1.59 (VDD12TX2)
/VDD33TXRX1: C13.1, C14.1, C28.1, FL2.2, J2.3 (TCT), J2.8 (RCT), R10.1, R11.1, R12.1, R13.1, U1.51 (VDD33TXRX1)
/VDD33TXRX2: C20.1, C21.1, C31.1, FL3.2, J4.3 (TCT), J4.8 (RCT), R17.1, R18.1, R19.1, R20.1, U1.64 (VDD33TXRX2)
/VDDCR: C16.1, C17.1, C18.1, C19.1, FL4.2, U1.6 (VDDCR), U1.24 (VDDCR), U1.38 (VDDCR)
GND: C5.2, C6.2, C7.2, C8.2, C9.2, C10.2, C11.1, C12.1, C13.2, C14.2, C15.1, C16.2, C17.2, C18.2, C19.2, C20.2, C21.2, C22.1, C23.1, C24.1, C25.1, C26.2, C27.1, C28.2, C29.1, C30.2, C31.2, C32.1, C33.2, D1.2 (A), D2.2 (A), J1.3, J1.6, J2.1, J2.SH, J4.1, J4.SH, J5.1, J6.1, R1.1, R2.1, R6.1, R7.1, R16.2, R27.2, SW1.1, SW1.2, U1.4 (OSCVSS), U1.8 (FXLOSEN), U1.9 (GND), U1.10 (GND), U1.41 (GND), U2.12 (VSSA), U2.18 (VSS), U2.31 (VSS), U2.47 (VSS), U2.63 (VSS), U3.4 (~EN), U3.5 (GND), U3.6 (GND), U3.7 (GND), U3.8 (GND), U4.4 (~EN), U4.5 (GND), U4.6 (GND), U4.7 (GND), U4.8 (GND), U5.5 (GND)
unnamed: C1.2, U2.19 (VDD)
unnamed: C2.2, U2.32 (VDD)
unnamed: C3.2, U2.48 (VDD)
unnamed: C4.2, U2.64 (VDD)
unnamed: D1.1 (K), L2.1, U3.2 (OUT)
unnamed: D2.1 (K), L3.1, U4.2 (OUT)
unnamed: F1.1, J6.2
unnamed: F1.2, Q1.1 (S), Q1.2 (S), Q1.3 (S), R15.1
unnamed: J2.2, R14.1
unnamed: J3.1, U2.20 (PA4)
unnamed: J3.2, U2.15 (PA1)
unnamed: J3.3, U2.14 (PA0)
unnamed: J4.2, R21.1
unnamed: J5.3, R26.2, R28.1, U5.6 (A)
unnamed: J5.4, R27.1, R28.2, U5.7 (B)
unnamed: Q1.4 (G), R15.2, R16.1
unnamed: R1.2, U1.57 (RBIAS)
unnamed: C12.2, FL1.2, U1.58 (VDD33BIAS)
unnamed: R2.2, U2.60 (BOOT0)
unnamed: R3.1, U2.21 (PA5)
unnamed: R29.1, U2.22 (PA6)
unnamed: R4.1, U2.23 (PA7)
unnamed: C23.2, U2.5 (PH0), Y2.2
unnamed: C25.2, U2.6 (PH1), Y2.1
unnamed: C27.2, U2.30 (VCAP_1)

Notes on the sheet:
Ajouter PLAN DE MASSE !
mettre R49.9 proche du LAN9252
Module STM32F446RE
OSC
Copper Port-B (OUT)
C13 & C14 close to pin6 (LAN9252)
Test Points
convertisseur +12V -> +3.3V
Module RS485
Copper Port-A (IN)
Power Supply Filtering (LAN9252)
Strap (LAN9252)
SWD Connector
convertisseur +12V -> +5V
Power
RESET CKT
LAN9252

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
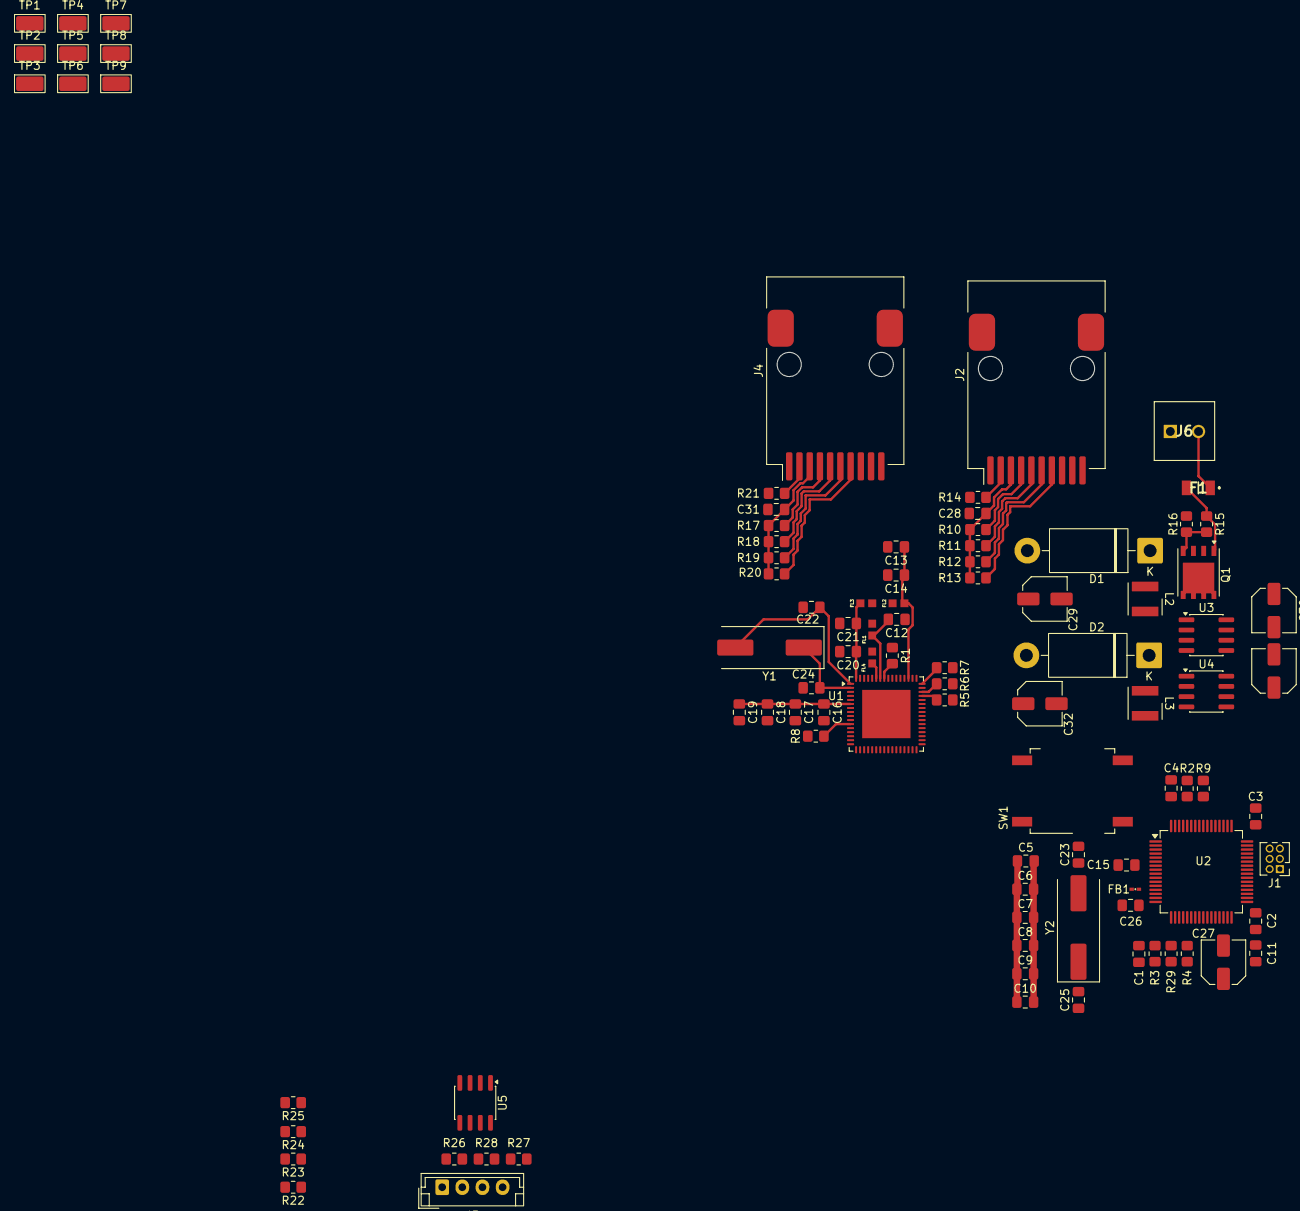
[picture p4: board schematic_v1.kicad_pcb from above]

Board: 2 copper layers, 95 parts (0 on the bottom side), 57 nets.

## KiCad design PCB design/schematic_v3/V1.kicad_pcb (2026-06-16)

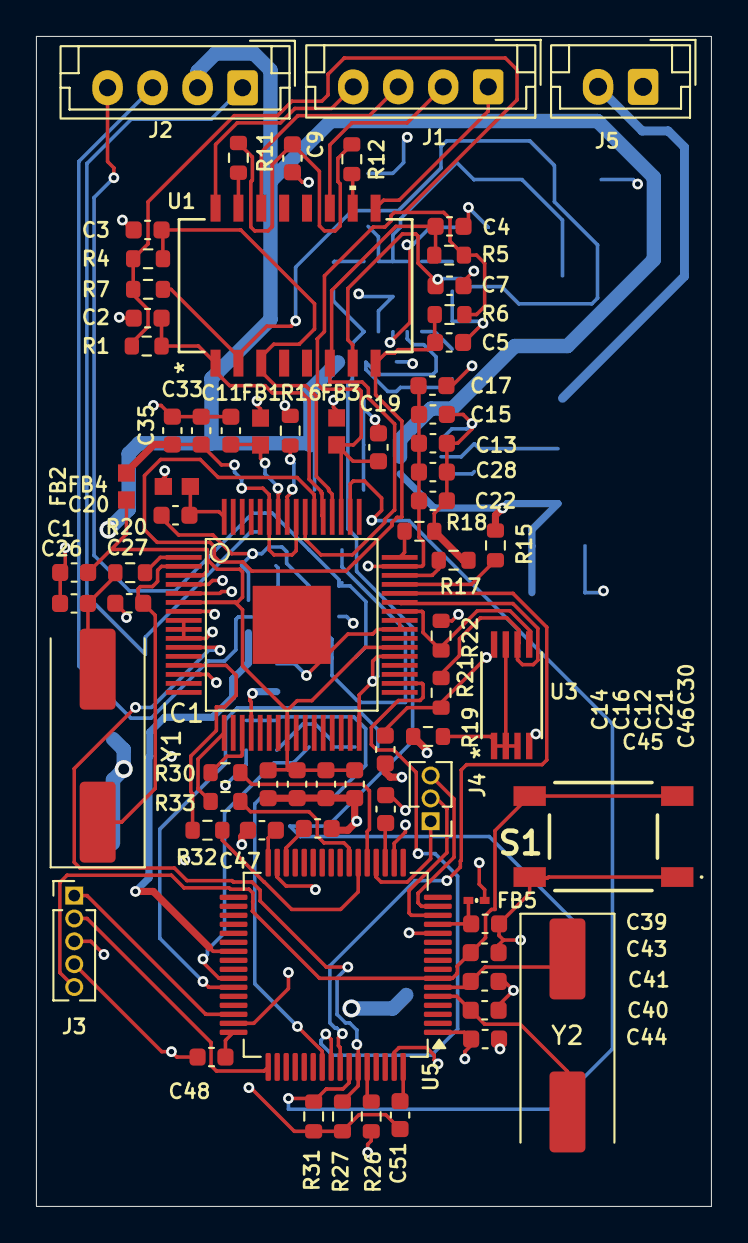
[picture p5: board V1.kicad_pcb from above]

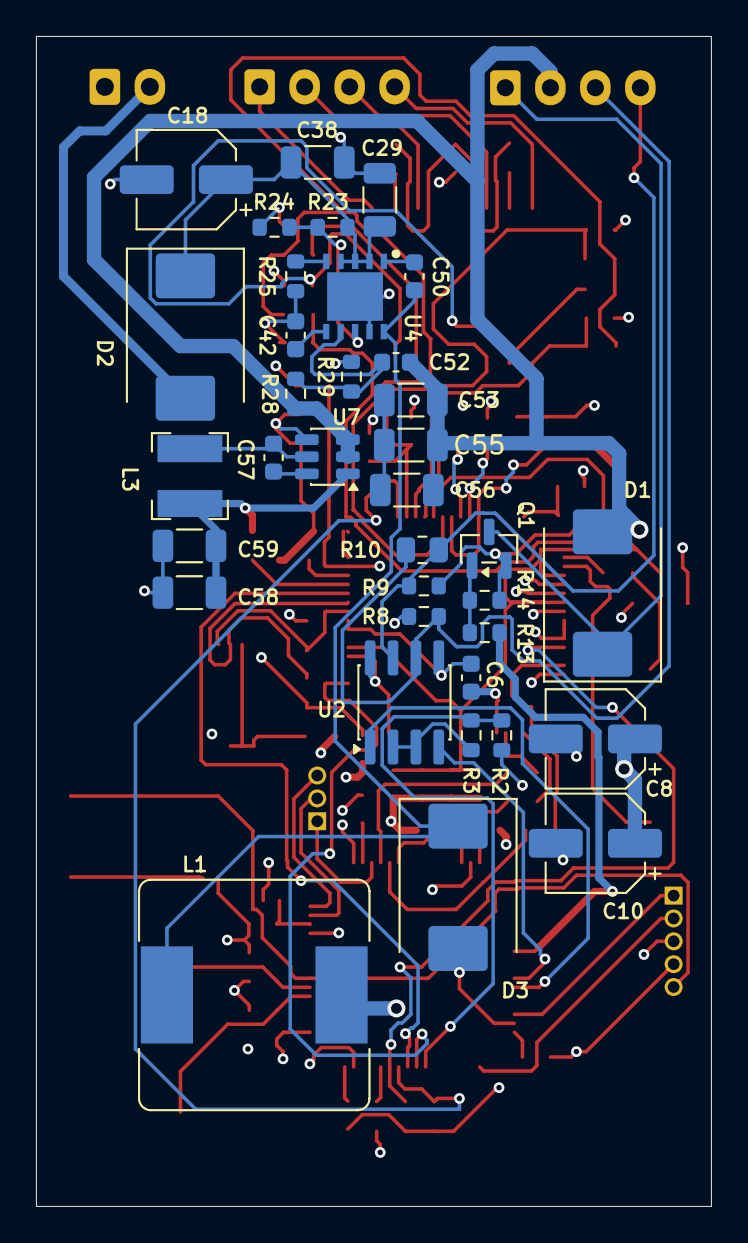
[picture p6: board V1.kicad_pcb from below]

Board: 4 copper layers, 37.5 x 65.0 mm, 108 parts (36 on the bottom side), 74 nets.

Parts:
C1, C6, C11, C13, C15, C16, C17, C21, C22, C28, C30, C33, C35: 0.1u; C_0603_1608Metric
C2, C3, C4, C5: 10p; C_0603_1608Metric
C7: 0.022u; C_0603_1608Metric
C8, C10, C18: 47u; CP_Elec_5x5.4
C9: 1n; C_0603_1608Metric
C12, C19, C20, C44: 1u; C_0603_1608Metric
C14: 470p; C_0603_1608Metric
C26, C27: 18p; C_0603_1608Metric
C29, C56: 10u; C_1206_3216Metric
C38: 100n; C_1206_3216Metric
C39, C42, C43, C46, C47, C48, C50, C51, C57: 100n; C_0603_1608Metric
C40, C41: 20p; C_0603_1608Metric
C45: 4.7u; C_0603_1608Metric
C52: 270p; C_0603_1608Metric
C53, C55: 27u; C_1206_3216Metric
C58, C59: 22u; C_1206_3216Metric
D1, D2, D3: B340; D_SMC
FB1, FB2, FB3, FB4: BLM18EG221SN1D; IND_BLM18_0603_MUR
FB5: MMZ0603A471ET000
IC1: TQFP64; LAN9252
J1: Conn_01x04_Pin; JST_EH_B4B-EH-A_1x04_P2.50mm_Vertical
J2: connection_moteur; JST_EH_B4B-EH-A_1x04_P2.50mm_Vertical
J3: Conn_01x05_Pin; PinHeader_1x05_P1.27mm_Vertical
J4: Conn_01x03_Pin; PinHeader_1x03_P1.27mm_Vertical
J5: Conn_01x02_Pin; JST_EH_B2B-EH-A_1x02_P2.50mm_Vertical
L1: 18u; L_Bourns_SRR1260
L3: 6.8u; L_Bourns-SRN4018
Q1: AO3400A; SOT-23
R1, R4, R5, R6: 49.9; R_0603_1608Metric
R2: 47k; R_0603_1608Metric
R3, R14, R15, R17, R18, R24, R26, R27, R29, R31: 10k; R_0603_1608Metric
R7, R20: 0; R_0603_1608Metric
R8, R9, R25: 20k; R_0603_1608Metric
R10: 120; R_0805_2012Metric
R11, R12: 75; R_0603_1608Metric
R13: 220; R_0603_1608Metric
R16: 12.1k; R_0603_1608Metric
R19: 4.7k; R_0603_1608Metric
R21, R22: 2k; R_0603_1608Metric
R23: 68k; R_0603_1608Metric
R28: 150k; R_0603_1608Metric
R30, R32, R33: 33; R_0603_1608Metric
S1: TS40-66-43-BK-260-SMT-TR
U1: HX1188NL
U2: SP3485CN; SOIC-8_3.9x4.9mm_P1.27mm
U3: 24FC512-I/ST; 24FC512_I_ST
U4: LMR14030SQDPRTQ1
U5: STM32F446RETx; LQFP-64_10x10mm_P0.5mm
U7: AP63203WU; TSOT-23-6
Y1: 25MHz; Crystal_SMD_HC49-SD
Y2: 8MHz; Crystal_SMD_HC49-SD

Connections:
+3.3V: C6.1, C13.1, C15.1, C17.1, C22.1, C28.1, C30.2, C44.2, C46.1, C47.1, C48.1, C51.1, C58.1, C59.1, FB1.1, FB3.2, FB4.2, FB5.1, IC1.5 (VDD33), IC1.7 (REG_EN), IC1.14 (VDDIO0), IC1.20 (VDDIO1), IC1.32 (VDDIO2), IC1.37 (VDDIO3), IC1.47 (VDDIO4), J3.4, L3.2, R8.2, R15.1, R21.2, R22.2, R27.1, R31.1, U2.8 (VCC), U3.8 (VCC), U5.1 (VBAT), U7.1 (FB)
+12V: C8.1, C10.1, C52.1, C53.1, C55.1, C56.1, D1.2 (A), J2.2, L1.2, R28.1, U7.2 (EN), U7.3 (IN)
+36V: D2.2 (A), J5.2
/ALIM_MOTOR: R13.2, U5.39 (PC8)
/AVDD: C39.1, FB5.2, U5.13 (VDDA)
/DI: U2.4 (DI), U5.42 (PA9)
/I2C_SCL: IC1.43 (EESCL/TCK), R21.1, U3.6 (SCL)
/I2C_SDL: IC1.42 (EESDA/TMS), R22.1, U3.5 (SDA)
/IRQ: IC1.44 (IRQ), U5.57 (PB5)
/MISO: IC1.13 (D1/AD1/EOF/SO/SIO1), R32.1
/MOSI: IC1.17 (D0/AD0/WD_STATE/SI/SIO0), R33.1
/NRST: C43.2, J3.5, S1.3 (NO_1), S1.4 (NO_2), U5.7 (NRST)
/OSCI: IC1.1 (OSCI), R20.1
/OSCO: C27.2, IC1.2 (OSCO), Y1.1
/RO: U2.1 (RO), U5.43 (PA10)
/RS485_MODE: R2.2, R3.2, U5.55 (PB3)
/RST#: IC1.11 (RST#), R27.2, U5.59 (PB7)
/RXA_N: C5.1, IC1.54 (RXNA), R6.2, U1.8 (RD-)
/RXA_P: C4.1, IC1.55 (RXPA), R5.2, U1.6 (RD+)
/SCK: IC1.19 (D9/AD9/LATCH_IN/SCK), R30.1
/SCS#: IC1.50 (D5/AD5/OUTVALID/SCS#), R31.2, U5.58 (PB6)
/SWCLK: J3.2, U5.49 (PA14)
/SWDIO: J3.1, U5.46 (PA13)
/SYNC0: IC1.34 (SYNC0/LATCH0), U5.56 (PB4)
/TXA_N: C3.1, IC1.52 (TXNA), R4.2, U1.3 (TD-)
/TXA_P: C2.1, IC1.53 (TXPA), R1.2, U1.1 (TD+)
/VDD12TX1: C33.1, C35.1, FB2.2, IC1.56 (VDD12TX1), IC1.59 (VDD12TX2)
/VDD33TXRX1: C19.1, FB3.1, IC1.51 (VDD33TXRX1), R1.1, R4.1, R5.1, R6.1, R7.1
/VDD33TXRX2: C20.1, FB4.1, IC1.64 (VDD33TXRX2)
/VDDCR: C1.2, C12.1, C14.1, C16.1, C21.1, FB2.1, IC1.3 (OSCVDD12), IC1.6 (VDDCR0), IC1.24 (VDDCR1), IC1.38 (VDDCR2)
GND: C1.1, C2.2, C3.2, C4.2, C5.2, C6.2, C7.2, C8.2, C9.2, C10.2, C11.1, C12.2, C13.2, C14.2, C15.2, C16.2, C17.2, C18.2, C19.2, C20.2, C21.2, C22.2, C26.1, C27.1, C28.2, C29.2, C30.1, C33.2, C35.2, C38.2, C39.2, C40.1, C41.1, C42.2, C43.1, C44.1, C45.2, C53.2, C55.2, C56.2, C58.2, C59.2, D3.2 (A), IC1.4 (OSCVSS), IC1.8 (FXLOSEN), IC1.9 (FXSDA/FXLOSA/FXSDENA), IC1.10 (FXSDB/FXLOSB/FXSDENB), IC1.40 (D8/AD8/DIGIO2/GPI2/GPO2/MII_MDIO), IC1.41 (TESTMODE), IC1.65 (VSS), J3.3, J5.1, Q1.2 (S), R2.1, R9.1, R14.1, R16.1, R17.1, R18.1, R19.2, R24.2, R25.2, R26.2, R29.2, S1.1 (COM_1), S1.2 (COM_2), U2.5 (GND), U3.4 (VSS), U4.9 (GND), U4.11 (PAD), U5.12 (VSSA), U5.18 (VSS), U5.31 (VSS), U5.47 (VSS), U5.63 (VSS), U7.4 (GND)
unnamed: C9.1, R11.1, R12.1
unnamed: C26.2, R20.2, Y1.2
unnamed: C46.2, U5.19 (VDD)
unnamed: C47.2, U5.32 (VDD)
unnamed: C48.2, U5.48 (VDD)
unnamed: C51.2, U5.64 (VDD)
unnamed: D1.1 (K), J2.1, Q1.3 (D)
unnamed: C18.1, C29.1, C38.1, D2.1 (K), R23.1, U4.2 (VIN), U4.3 (VIN), U4.4 (EN)
unnamed: C50.2, D3.1 (K), L1.1, U4.10 (SW)
unnamed: IC1.48 (LINKACTLED0/TDO/CHIP_MODE0), R18.2
unnamed: IC1.46 (LINKACTLED1/TDI/CHIP_MODE1), R17.2
unnamed: IC1.57 (RBIAS), R16.2
unnamed: IC1.45 (RUNLED/E2PSIZE), R15.2
unnamed: C11.2, FB1.2, IC1.58 (VDD33BIAS)
unnamed: J1.1, U1.9 (RX-)
unnamed: J1.2, U1.11 (RX+)
unnamed: J1.3, U1.14 (TX-)
unnamed: J1.4, U1.16 (TX+)
unnamed: J2.3, R8.1, R10.2, U2.6 (A)
unnamed: J2.4, R9.2, R10.1, U2.7 (B)
unnamed: J4.1, U5.20 (PA4)
unnamed: J4.2, U5.14 (PA0)
unnamed: J4.3, U5.15 (PA1)
unnamed: Q1.1 (G), R13.1, R14.2
unnamed: R11.2, U1.15 (CMT)
unnamed: R12.2, U1.10 (CMT)
unnamed: C7.1, R7.2, U1.2 (TCT), U1.7 (RCT)
unnamed: R3.1, U2.2 (~RE), U2.3 (DE)
unnamed: R19.1, U3.1 (A0), U3.2 (A1), U3.3 (A2), U3.7 (WP)
unnamed: C50.1, U4.1 (BOOT)
unnamed: C52.2, R28.2, R29.1, U4.7 (FB)
unnamed: R23.2, R24.1, U4.8 (PGOOD)
unnamed: R25.1, U4.5 (RT_SYNC)
unnamed: C42.1, U4.6 (SS)
unnamed: R26.1, U5.60 (BOOT0)
unnamed: R30.2, U5.21 (PA5)
unnamed: R32.2, U5.22 (PA6)
unnamed: R33.2, U5.23 (PA7)
unnamed: C40.2, U5.5 (PH0), Y2.2
unnamed: C41.2, U5.6 (PH1), Y2.1
unnamed: C45.1, U5.30 (VCAP_1)
unnamed: C57.2, U7.6 (BST)
unnamed: C57.1, L3.1, U7.5 (SW)

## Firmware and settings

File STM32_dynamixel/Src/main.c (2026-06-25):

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
/* Includes ------------------------------------------------------------------*/
#include "main.h"

/* USER CODE BEGIN Includes */
#include "drv_gpio.h"
#include "drv_uart.h"
#include "FreeRTOS.h"
#include "task.h"
#include "cmsis_os2.h"
#include "ECAT/soes/ecat_slv.h"
#include "ECAT/soes/esc.h"
#include "ECAT/soes-esi/utypes.h"
#include "motor_sm.h"

#define TEST	0
/* USER CODE END Includes */

/* USER CODE BEGIN PTD */
_Objects Obj;
motor_command_t motor_cmd1;
motor_status_t motor_status1;
motor_context_t motor_ctx1;
SemaphoreHandle_t mutex_motor;
DMA_HandleTypeDef hdma_usart1_rx;

extern uint8_t rec_buf1[];

static esc_cfg_t config = { .user_arg = "/dev/lan9252", .use_interrupt = 0,
		.watchdog_cnt = 500, .set_defaults_hook = NULL, .pre_state_change_hook =
		NULL, .post_state_change_hook = NULL, .application_hook = NULL,
		.safeoutput_override = NULL, .pre_object_download_hook = NULL,
		.post_object_download_hook = NULL, .rxpdo_override = NULL,
		.txpdo_override = NULL, .esc_hw_interrupt_enable = NULL,
		.esc_hw_interrupt_disable = NULL, .esc_hw_eep_handler = NULL,
		.esc_check_dc_handler = NULL, };

extern volatile uint32_t dbg_time_localtime;
extern volatile uint32_t dbg_time_state;
extern volatile uint32_t dbg_time_smact;
extern volatile uint32_t dbg_time_mbxprocess;
extern volatile uint32_t dbg_time_coeprocess;
extern volatile uint32_t dbg_time_xoeprocess;
extern volatile uint32_t dbg_time_eephandler;

extern volatile uint32_t dbg_time_rxpdoupdate;
extern volatile uint32_t dbg_time_setoutputs;
extern volatile uint32_t dbg_time_getinputs;
extern volatile uint32_t dbg_time_txpdoupdate;

/* USER CODE END PTD */


void SystemClock_Config(void);

/* USER CODE BEGIN 0 */
#define ID_1			1
#define BUFFER_LENGTH	128
void MX_DMA_Init(void);

void cb_get_inputs() {
	Obj.ID_TX = motor_status1.id;
	Obj.state = (uint8_t) motor_status1.state;
	Obj.present_position = motor_status1.present_position;
	Obj.present_velocity = motor_status1.present_velocity;
	Obj.present_current = motor_status1.present_current;
	Obj.present_temperature = motor_status1.present_temperature;
	Obj.baudrate = motor_status1.baudrate;
	Obj.operating_mode = motor_status1.control_mode_st;
	Obj.Max_pos_lim = motor_status1.Max_pos_lim;
	Obj.Min_pos_lim = motor_status1.Min_pos_lim;
	Obj.Velocity_lim = motor_status1.Velocity_lim;
	Obj.Current_lim = motor_status1.Current_lim;
	Obj.Hardware_error_status = motor_status1.Hardware_error_status;
	Obj.Moving = motor_status1.Moving;
	Obj.torque_status = motor_status1.torque_status;
}

void cb_set_outputs() {
	motor_update_master_watchdog();
	if (motor_ctx1.current_state == &state_init)
		return;
	motor_cmd1.id = Obj.ID_RX;
	motor_cmd1.control_mode = Obj.control_mode;
	motor_cmd1.torque_enabled = Obj.torque_enabled;
	motor_cmd1.LED_state = Obj.LED_STATE;
	motor_cmd1.reboot = Obj.Reboot;
	motor_cmd1.emergency_stop = Obj.Emergency_stop;

	if (!motor_ctx1.post_comm_loss) {
		motor_cmd1.target_position = Obj.goal_position;
		motor_cmd1.target_velocity = Obj.target_velocity;
		motor_cmd1.target_current = Obj.target_current;
	}

}
/* USER CODE END 0 */

/**
 * @brief  The application entry point.
 * @retval int
 */

volatile uint8_t ecat_operational = 0;

static void task_EtherCAT(void *pvParameters) {
	while (!ecat_operational) {
		ecat_slv();
		if ((ESCvar.App.state & APPSTATE_OUTPUT) > 0) {
			ecat_operational = 1;
			term_printf("[TIM-001]EtherCAT OP reached!\r\n");
		}
		vTaskDelay(pdMS_TO_TICKS(1));
	}

	TickType_t xLastWakeTime = xTaskGetTickCount();
//	uint32_t print_divider = 0;
//	uint32_t max_cycles = 0;
	for (;;) {
//		uint32_t t_start = DWT->CYCCNT;
		ecat_slv();
//		uint32_t t_elapsed = DWT->CYCCNT - t_start;

//		if (t_elapsed > max_cycles) {
//			max_cycles = t_elapsed;
//		}
//		if (++print_divider >= 1000) {  // affiche toutes les ~1s à 1ms de cycle
//			print_divider = 0;
//			uint32_t us = max_cycles / (SystemCoreClock / 1000000);
////			term_printf("[DBG] ecat_slv max=%u us (over last 1000 cycles)\r\n",
////					us);
//			max_cycles = 0;
////			term_printf("[DBG] ESC_READ max=%u us \r\n", dbg_time_localtime);
////			term_printf("[DBG] ESC_STATE max=%u us \r\n", dbg_time_state);
////			term_printf("[DBG] ESC_SM_ACT max=%u us \r\n", dbg_time_smact);
////			term_printf("[DBG] mbx_process max=%u us \r\n",
////					dbg_time_mbxprocess);
////			term_printf("[DBG] coe_process max=%u us \r\n",
////					dbg_time_coeprocess);
////			term_printf("[DBG] xoe_process max=%u us \r\n",
////					dbg_time_xoeprocess);
////			term_printf("[DBG] eephandler max=%u us \r\n", dbg_time_eephandler);
//
////			term_printf("[DBG] rxpdo update max=%u us \r\n",
////					dbg_time_rxpdoupdate);
////			term_printf("[DBG] set_outputs max=%u us \r\n",
////					dbg_time_setoutputs);
////			term_printf("[DBG] get_inputs max=%u us \r\n", dbg_time_getinputs);
////			term_printf("[DBG] txpdo update max=%u us \r\n",
////					dbg_time_txpdoupdate);
//		}
		vTaskDelayUntil(&xLastWakeTime, pdMS_TO_TICKS(1));
	}
}

static void task_motor(void *pvParameters) {
	while (!ecat_operational) {
		vTaskDelay(pdMS_TO_TICKS(50));
	}
	motor_update_master_watchdog();

	for (;;) {
		if (xSemaphoreTake(mutex_motor, pdMS_TO_TICKS(10))) {
			motor_sm_update(&motor_ctx1);
			xSemaphoreGive(mutex_motor);
		}
		vTaskDelay(pdMS_TO_TICKS(5));
	}
}

#define RELAY_PIN   GPIO_PIN_8
#define RELAY_PORT  GPIOC

void RELAY_On(void) {
	HAL_GPIO_WritePin(RELAY_PORT, RELAY_PIN, GPIO_PIN_SET);
}
void RELAY_Off(void) {
	HAL_GPIO_WritePin(RELAY_PORT, RELAY_PIN, GPIO_PIN_RESET);
}

int main(void) {

	/* MCU Configuration--------------------------------------------------------*/

	/* Reset of all peripherals, Initializes the Flash interface and the Systick. */

	HAL_Init();
	CoreDebug->DEMCR |= CoreDebug_DEMCR_TRCENA_Msk;
	DWT->CYCCNT = 0;
	DWT->CTRL |= DWT_CTRL_CYCCNTENA_Msk;
	/* Configure the system clock */
	SystemClock_Config();

	/* Initialize all configured peripherals */
	MX_GPIO_Init();
	MX_DMA_Init();
	HAL_GPIO_WritePin(GPIOC, GPIO_PIN_8, GPIO_PIN_SET);
	MX_USART1_UART_Init();
	MX_USART2_UART_Init();
	dynamixel2_dma_init();
	/* USER CODE BEGIN 2 */
	term_printf("\n\r===== Boot =====\r\n");
#if TEST == 0
	ecat_slv_init(&config);

	//motor_init(ID_1, &motor_cmd1, &motor_status1);
	motor_sm_init(&motor_ctx1, &motor_cmd1, &motor_status1, ID_1);

	/* USER CODE END 2 */
	mutex_motor = xSemaphoreCreateMutex();
	osKernelInitialize();
	xTaskCreate(task_EtherCAT, "ECAT", 1024, NULL, 32, NULL);

	xTaskCreate(task_motor, "MOTOR", 1024, NULL, 22, NULL);

	osKernelStart();
	/* USER CODE BEGIN WHILE */
#else

	RELAY_Off();

	while (1) {
		RELAY_On();
		term_printf("\n\r\n\rALLUMÉ\n\r\n\r");
		HAL_Delay(1000); /* charge ON pendant 1s */

		RELAY_Off();
		term_printf("\n\r\n\rÉTEINT\n\r\n\r");
		HAL_Delay(1000); /* charge OFF pendant 1s */
	}

#endif

}
/* USER CODE END 3 */

void SystemClock_Config(void) {
	RCC_OscInitTypeDef RCC_OscInitStruct = { 0 };
	RCC_ClkInitTypeDef RCC_ClkInitStruct = { 0 };

	__HAL_RCC_PWR_CLK_ENABLE();
	__HAL_PWR_VOLTAGESCALING_CONFIG(PWR_REGULATOR_VOLTAGE_SCALE1);

	/* HSI 16 MHz -> PLL -> 180 MHz */
	RCC_OscInitStruct.OscillatorType = RCC_OSCILLATORTYPE_HSI;
	RCC_OscInitStruct.HSIState = RCC_HSI_ON;
	RCC_OscInitStruct.HSICalibrationValue = RCC_HSICALIBRATION_DEFAULT;
	RCC_OscInitStruct.PLL.PLLState = RCC_PLL_ON;
	RCC_OscInitStruct.PLL.PLLSource = RCC_PLLSOURCE_HSI;
	RCC_OscInitStruct.PLL.PLLM = 8; /* HSI/8 = 2 MHz */
	RCC_OscInitStruct.PLL.PLLN = 180; /* 2*180 = 360 MHz VCO */
	RCC_OscInitStruct.PLL.PLLP = RCC_PLLP_DIV2; /* 360/2 = 180 MHz SYSCLK */
	RCC_OscInitStruct.PLL.PLLQ = 8; /* pour USB si besoin */
	if (HAL_RCC_OscConfig(&RCC_OscInitStruct) != HAL_OK) {
		Error_Handler();
	}

	if (HAL_PWREx_EnableOverDrive() != HAL_OK) {
		Error_Handler();
	}

	RCC_ClkInitStruct.ClockType = RCC_CLOCKTYPE_HCLK | RCC_CLOCKTYPE_SYSCLK
			| RCC_CLOCKTYPE_PCLK1 | RCC_CLOCKTYPE_PCLK2;
	RCC_ClkInitStruct.SYSCLKSource = RCC_SYSCLKSOURCE_PLLCLK;
	RCC_ClkInitStruct.AHBCLKDivider = RCC_SYSCLK_DIV1; /* HCLK = 180 MHz */
	RCC_ClkInitStruct.APB1CLKDivider = RCC_HCLK_DIV4; /* APB1 = 45 MHz */
	RCC_ClkInitStruct.APB2CLKDivider = RCC_HCLK_DIV2; /* APB2 = 90 MHz */

	/* IMPORTANT : Flash latency 5 WS pour 180 MHz */
	if (HAL_RCC_ClockConfig(&RCC_ClkInitStruct, FLASH_LATENCY_5) != HAL_OK) {
		Error_Handler();
	}
}

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


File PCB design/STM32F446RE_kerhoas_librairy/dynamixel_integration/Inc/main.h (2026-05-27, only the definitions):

#define B1_Pin GPIO_PIN_13
#define B1_GPIO_Port GPIOC
#define USART_TX_Pin GPIO_PIN_2
#define USART_TX_GPIO_Port GPIOA
#define USART_RX_Pin GPIO_PIN_3
#define USART_RX_GPIO_Port GPIOA
#define TMS_Pin GPIO_PIN_13
#define TMS_GPIO_Port GPIOA
#define TCK_Pin GPIO_PIN_14
#define TCK_GPIO_Port GPIOA

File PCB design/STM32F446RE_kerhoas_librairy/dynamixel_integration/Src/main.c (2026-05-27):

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
/* Includes ------------------------------------------------------------------*/
#include "main.h"

/* USER CODE BEGIN Includes */
#include "math.h"
#include "util.h"
#include "dynamixel.h"
#include "stm32f4xx.h"

/* USER CODE END Includes */

/* USER CODE BEGIN PD */
#define DYN_ID	1
#define	USE_USART_STLINK 1
#define NB_CAR_TO_RECEIVE		1		// nombre de caractères à recevoir pour déclencher une interruption

/* USER CODE END PD */

SPI_HandleTypeDef hspi1;

UART_HandleTypeDef huart2;
UART_HandleTypeDef huart6;

void SystemClock_Config(void);
static void MX_GPIO_Init(void);
static void MX_SPI1_Init(void);
static void MX_USART2_UART_Init(void);
static void MX_USART6_UART_Init(void);
/* USER CODE BEGIN PFP */
int put_char(char);

uint8_t rec_buf2[NB_CAR_TO_RECEIVE+1]="";
uint8_t rec_buf6[NB_CAR_TO_RECEIVE+1]="";
/* USER CODE END PFP */

/**
  * @brief  The application entry point.
  * @retval int
  */
int main(void)
{

  /* MCU Configuration--------------------------------------------------------*/

  /* Reset of all peripherals, Initializes the Flash interface and the Systick. */
  HAL_Init();

  /* Configure the system clock */
  SystemClock_Config();

  /* Initialize all configured peripherals */
  MX_GPIO_Init();
  MX_SPI1_Init();
  MX_USART2_UART_Init();
  MX_USART6_UART_Init();
  /* USER CODE BEGIN 2 */
  char txt[] = "HELLO\r\n";
  HAL_UART_Transmit(&huart2, (uint8_t*)txt, sizeof(txt)-1, 1000);  /* USER CODE END 2 */

  /* Infinite loop */
  /* USER CODE BEGIN WHILE */
  while (1)
  {
    /* USER CODE END WHILE */

    /* USER CODE BEGIN 3 */
  }
  /* USER CODE END 3 */
}

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
/* USER CODE BEGIN 4 */
//=================================================================
//	PUCHAR PROTOTYPE (USED BY PRINTF FUNCTIONS)
//=================================================================
int put_char(char ch)
{
#if USE_USART_STLINK
	HAL_UART_Transmit(&huart2, (uint8_t *)&ch, 1, 0xFFFF);
#else
	HAL_UART_Transmit(&huart6, (uint8_t *)&ch, 1, 0xFFFF);
#endif
  return 0;
}


//=================================================================
//	UART RECEIVE CALLBACK5
//=================================================================
void HAL_UART_RxCpltCallback(UART_HandleTypeDef *UartHandle)
{
	if (UartHandle -> Instance == USART6)
	{
		HAL_UART_Receive_IT(&huart6, (uint8_t *)rec_buf6, NB_CAR_TO_RECEIVE);
		dxl_rcv_cb(rec_buf6[0]);
	}
	/*else
	if (UartHandle -> Instance == USART2)
	{
		HAL_UART_Receive_IT(&huart2, (uint8_t *)rec_buf2, NB_CAR_TO_RECEIVE);
	}*/

}
//================================================================
//				PUT STRING
//================================================================
void put_string(char* s)
{
	while(*s != '\0')
	{
		put_char(*s);
		s++;
	}
}

void sendFrame(unsigned char* s, int size)
{
	HAL_UART_Transmit(&huart6, s, size, 1000);

	 while (__HAL_UART_GET_FLAG(&huart6, UART_FLAG_TC) == RESET)
	 {
	 }
}


//================================================================
//				TERM_PRINTF
//================================================================

void term_printf(const char* fmt, ...)
{
	__gnuc_va_list         ap;
	char          *p;
	char           ch;
	unsigned long  ul;
	unsigned long long ull;
	unsigned long  size;
	unsigned int   sp;
	char           s[60];
	int first=0;

	va_start(ap, fmt);

	while (*fmt != '\0') {
		if (*fmt =='%') {
			size=0; sp=1;
			if (*++fmt=='0') {fmt++; sp=0;}	// parse %04d --> sp=0
			ch=*fmt;
			if ((ch>'0') && (ch<='9')) {	// parse %4d --> size=4
				char tmp[10];
				int i=0;
				while ((ch>='0') && (ch<='9')) {
					tmp[i++]=ch;
					ch=*++fmt;
				}
				tmp[i]='\0';
				size=str2num(tmp,10);
			}
			switch (ch) {
				case '%':
					put_char('%');
					break;
				case 'c':
					ch = va_arg(ap, int);
					put_char(ch);
					break;
				case 's':
					p = va_arg(ap, char *);
					put_string(p);
					break;
				case 'd':
					ul = va_arg(ap, long);
					if ((long)ul < 0) {
						put_char('-');
						ul = -(long)ul;
						//size--;
					}
					num2str(s, ul, 10, size, sp);
					put_string(s);
					break;
				case 'u':
					ul = va_arg(ap, unsigned int);
					num2str(s, ul, 10, size, sp);
					put_string(s);
					break;
				case 'o':
					ul = va_arg(ap, unsigned int);
					num2str(s, ul, 8, size, sp);
					put_string(s);
					break;
				case 'p':
					put_char('0');
					put_char('x');
					ul = va_arg(ap, unsigned int);
					num2str(s, ul, 16, size, sp);
					put_string(s);
					break;
				case 'x':
					ul = va_arg(ap, unsigned int);
					num2str(s, ul, 16, size, sp);
					put_string(s);
					break;
				case 'f':
					if(first==0){ ull = va_arg(ap, long long unsigned int); first = 1;}
					ull = va_arg(ap, long long unsigned int);
					int sign = ( ull & 0x80000000 ) >> 31;
					int m = (ull & 0x000FFFFF) ; // should be 0x007FFFFF
					float mf = (float)m ;
					mf = mf / pow(2.0,20.0);
					mf = mf + 1.0;
					int e = ( ull & 0x78000000 ) >> 23 ; // should be int e = ( ul & 0x7F800000 ) >> 23;
					e = e | (( ull & 0x000F00000 ) >> 20);
					e = e - 127;
					float f = mf*myPow(2.0,e);
					if(sign==1){ put_char('-'); }
					float2str((char*)s, f, 5);
					put_string((char*)s);
					break;

				default:
					put_char(*fmt);
			}
		} else put_char(*fmt);
		fmt++;
	}
	va_end(ap);
}
/* USER CODE END 4 */
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


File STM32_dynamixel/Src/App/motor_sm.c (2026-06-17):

#include "motor_sm.h"
#include "motor_app.h"
#include "dynamixel_2_0.h"
#include "util.h"
#include "main.h"

#define Init_MAX_limit		4095
#define Init_MIN_limit		0
#define HW_EMRG_CLEAR_TEMP	60u
#define RECONNECT_PERIOD_MS 500u

#define With_GRIPPER		0



void motor_transition_to(motor_context_t *ctx,
		const motor_sm_state_t *new_state) {
	if (ctx->current_state && ctx->current_state->exit) {
		ctx->current_state->exit(ctx);
	}
	term_printf("[SM] %s -> %s\r\n",
			ctx->current_state ? ctx->current_state->name : "none",
			new_state->name);

	ctx->current_state = new_state;

	if (ctx->current_state->enter) {
		ctx->current_state->enter(ctx);
	}
}

void motor_sm_update(motor_context_t *ctx) {
	if (ctx->current_state && ctx->current_state->update)
		ctx->current_state->update(ctx);
}

static void read_motor_sensors(motor_context_t *ctx) {
	uint8_t id = ctx->status->id;

	uint16_t address = 122;
	uint16_t size = 14;
	uint8_t return_data[size];
	uint16_t return_data_length;
	dynamixel2_read(id, address, size, return_data, &return_data_length);

	ctx->status->Moving = return_data[0];
	ctx->status->present_current = return_data[4]
			+ ((return_data[5] << 8) & 0xFF00);
	ctx->status->present_velocity = return_data[6]
			+ ((return_data[7] << 8) & 0xFF00)
			+ ((return_data[8] << 16) & 0xFF0000)
			+ ((return_data[9] << 24) & 0xFF000000);
	ctx->status->present_position = return_data[10]
			+ ((return_data[11] << 8) & 0xFF00)
			+ ((return_data[12] << 16) & 0xFF0000)
			+ ((return_data[13] << 24) & 0xFF000000);

	switch (ctx->read_cycle) {
	case 0:
		ctx->status->present_temperature = dynamixel2_read_present_temperature(
				id);
		break;
	case 1:
		ctx->status->control_mode_st = dynamixel2_getOperatingMode(id);
		break;
	case 2:
		ctx->status->Hardware_error_status = dynamixel2_hardware_error(id);
		break;
	}
	ctx->read_cycle = (ctx->read_cycle + 1) % 3;
}

static void apply_motor_command(motor_context_t *ctx) {
	uint8_t id = ctx->cmd->id;
	dynamixel2_set_LED(id, ctx->cmd->LED_state);

	if (ctx->cmd->control_mode != ctx->status->control_mode_st) {
		dynamixel2_set_torque_enable(id, 0);
		dynamixel2_setOperatingMode(id, ctx->cmd->control_mode);
		ctx->status->control_mode_st = ctx->cmd->control_mode;
		dynamixel2_set_torque_enable(id, ctx->cmd->torque_enabled);
	} else {
		dynamixel2_set_torque_enable(id, ctx->cmd->torque_enabled);
	}
	switch (ctx->cmd->control_mode) {
	case POSITION_MODE:
		dynamixel2_set_goal_position(id, ctx->cmd->target_position);
		break;
	case VELOCITY_MODE:
		dynamixel2_set_goal_velocity(id, ctx->cmd->target_velocity);
		break;
	case CURRENT_MODE:
		dynamixel2_set_goal_current(id, ctx->cmd->target_current);
		break;
	default:
		break;
	}
}

static uint8_t check_safety(motor_context_t *ctx) {
	if (ctx->cmd->emergency_stop) {
		motor_transition_to(ctx, &state_sw_emergency);
		return 1;
	}

	if (motor_master_timed_out()) {
		motor_transition_to(ctx, &state_comm_loss);
		return 1;
	}

	if (ctx->status->present_temperature > 70
			|| ctx->status->Hardware_error_status != 0) {
		motor_transition_to(ctx, &state_hw_emergency);
		return 1;
	}

	return 0;
}

static void state_init_enter(motor_context_t *ctx) {
	uint8_t id = ctx->cmd->id;
	ctx->status->id = id;
	ctx->status->state = MOTOR_STATE_INIT;

	ctx->cmd->LED_state = 0;
	ctx->cmd->target_position = 0;
	ctx->cmd->target_velocity = 0;
	ctx->cmd->target_current = 0;
	ctx->cmd->control_mode = POSITION_MODE;
	ctx->cmd->torque_enabled = 0;
	ctx->status->present_position = 0;
	ctx->status->present_velocity = 0;
	ctx->status->present_current = 0;
	ctx->status->present_temperature = 0;
	ctx->ping_error_count = 0;

	term_printf("\r\n[INIT-001] Dynamixel XM430-W350 init...\r\n");
	if (!dynamixel2_ping(id)) {
		term_printf("[INIT-001] Connection to motor failed.\r\n\r\n");
		motor_transition_to(ctx, &state_error);
		return;
	}
#if With_GRIPPER
	dynamixel2_set_torque_enable(id, 0);
	dynamixel2_setOperatingMode(id,VELOCITY_MODE);
	dynamixel2_set_torque_enable(id, 1);
	dynamixel2_set_goal_velocity(id, 0);

	do{dynamixel2_set_goal_velocity(id, 50);}
	while(HAL_GPIO_ReadPin(GPIOA, GPIO_PIN_0)!=GPIO_PIN_RESET);
	dynamixel2_set_goal_velocity(id, 0);
	HAL_Delay(500);

	ctx->status->Max_pos_lim = (((dynamixel2_read_present_position(id)%4096)+4096)%4096)-20;
	dynamixel2_set_torque_enable(id, 0);
	dynamixel2_setMaxPositionLimit(id, ctx->status->Max_pos_lim);
	term_printf("[INIT-002] First limit saved\r\n");
	dynamixel2_set_torque_enable(id, 1);
	HAL_Delay(100);

	do{dynamixel2_set_goal_velocity(id, -50);}
	while(HAL_GPIO_ReadPin(GPIOA, GPIO_PIN_1)!=GPIO_PIN_RESET);
	dynamixel2_set_goal_velocity(id, 0);
	HAL_Delay(100);

	ctx->status->Min_pos_lim = (((dynamixel2_read_present_position(id)%4096)+4096)%4096)+20;
	dynamixel2_set_torque_enable(id, 0);
	dynamixel2_setMinPositionLimit(id, ctx->status->Min_pos_lim);
	term_printf("[INIT-002] Second limit saved!\r\n");

	dynamixel2_setOperatingMode(id, ctx->cmd->control_mode);
	dynamixel2_set_torque_enable(id, 1);
	int32_t mid = (ctx->status->Max_pos_lim + ctx->status->Min_pos_lim)/2;
	dynamixel2_set_goal_position(id, mid);
	HAL_Delay(500);

	ctx->cmd->torque_enabled = 0;
	dynamixel2_set_torque_enable(id, 0);
#else
	ctx->status->Max_pos_lim = Init_MAX_limit;
	ctx->status->Min_pos_lim = Init_MIN_limit;

	dynamixel2_set_torque_enable(id, 0);
	dynamixel2_setMaxPositionLimit(id, Init_MAX_limit);
	dynamixel2_setMinPositionLimit(id, Init_MIN_limit);
	dynamixel2_setOperatingMode(id, ctx->cmd->control_mode);
	dynamixel2_set_torque_enable(id, 1);
	dynamixel2_set_goal_position(id, ctx->cmd->target_position);
	term_printf("[INIT-002] Software limits saved! \r\n");
#endif
	ctx->status->Current_lim = dynamixel2_getCurrentLimit(id);
	ctx->status->Velocity_lim = dynamixel2_getVelocityLimit(id);
	ctx->status->control_mode_st = dynamixel2_getOperatingMode(id);
	ctx->status->baudrate = dynamixel2_get_BaudRate(id);
	if (ctx->post_comm_loss) {
		ctx->cmd->torque_enabled = 0;
		dynamixel2_set_torque_enable(id, 0);
	} else {
		ctx->cmd->torque_enabled = 1;
	}

	term_printf("[INIT-001] Dynamixel XM430-W350 OK!\r\n\r\n");

#if With_GRIPPER
	motor_transition_to(ctx, &state_gripper);
#else
	motor_transition_to(ctx, &state_operational);
#endif
}

const motor_sm_state_t state_init = { .enter = state_init_enter, .update = NULL,
		.exit = NULL, .name = "INIT", };
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

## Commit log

2026-04-16 mise a jour partie eepromtool
    [lan9252_spi.xlsx]
2026-04-22 Developpement des Input/Output
2026-04-22 ajout des conditions limites
2026-04-23 update of the control current
2026-04-24 ajout des sensors
2026-04-28 ajout de la détection de limite
2026-04-28 ajout de la fonction reboot
    [dynamixel_2_0.c, dynamixel_2_0.h, motor_app.c]
2026-04-29 reboot après emergency state
    [motor_app.c]
2026-05-27 update pcb design
    [Connectors.kicad_sch, MB1136.kicad_sch, MCU_64.kicad_sch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]
2026-06-16 pcb updated
    [ECAT_robot_gripper.csv, V1.kicad_pcb, bom.csv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]
2026-06-17 1KHz ecat communication frequency done
    [schematic_v3.kicad_pcb, schematic_v3.kicad_sch]
2026-06-25 PCB ordered
    [bom.csv, designators.csv, positions.csv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]

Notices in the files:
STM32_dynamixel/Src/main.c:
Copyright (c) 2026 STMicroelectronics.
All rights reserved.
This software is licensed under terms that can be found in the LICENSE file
